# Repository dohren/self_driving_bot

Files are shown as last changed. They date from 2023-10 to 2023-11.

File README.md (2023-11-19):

# self-driving-bot

## Introduction

This documentation provides an overview of a ROS2 package found in a specific repository designed for transforming an Ikea changing table into a self-driving robot. This innovative project takes a budget-friendly approach by utilizing an inexpensive, second-hand Ikea changing table and equipping it with essential robotic components to enable autonomous movement.

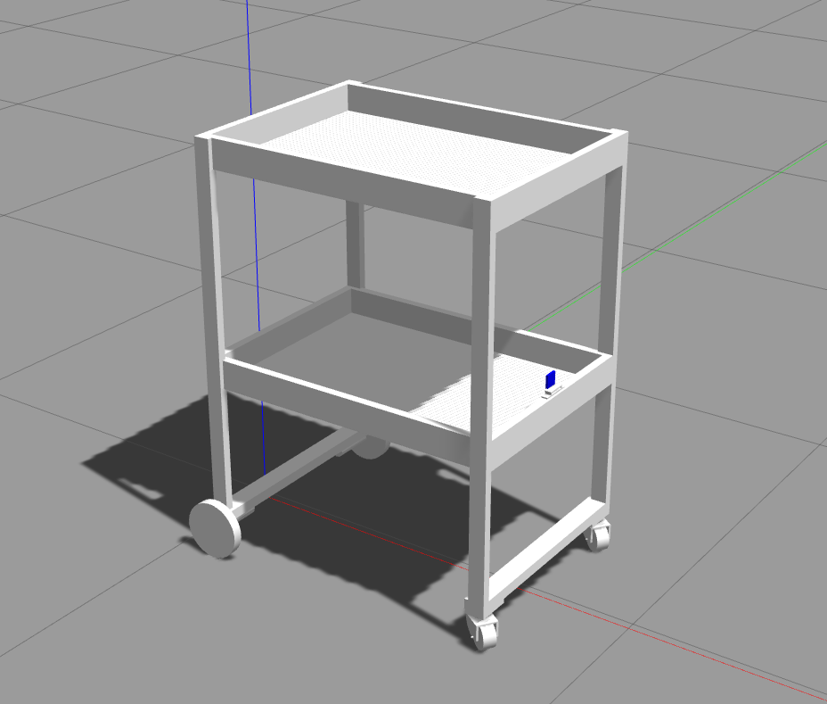
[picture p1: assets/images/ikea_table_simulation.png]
IKEA TABLE SIMULATION IKEA table simulation

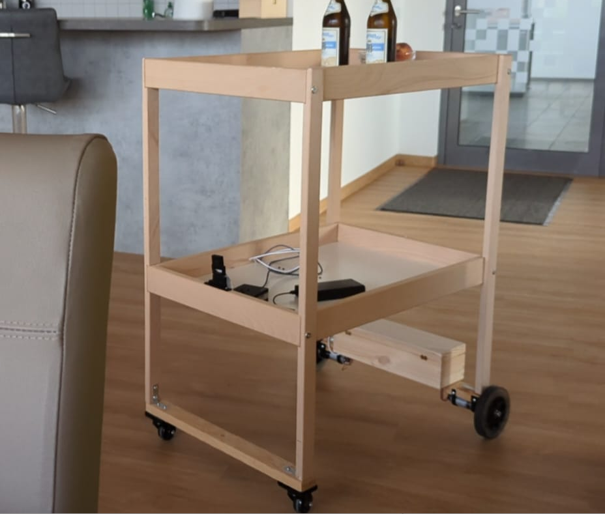
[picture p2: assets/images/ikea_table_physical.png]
IKEA TABLE PHYSICAL IKEA table physical


## Core Components and Assembly
### 1. Ikea Changing Table:

The project’s foundation is built on a used Ikea changing table, acquired at an approximate cost of 15 Euros.

### 2. Motion Mechanism:

Two 12V DC Motors: Installed at the rear to facilitate the robot’s movement.
Two Furniture Casters: Attached at the front for easy and smooth directional shifts.
Two Roof Battens: Utilized possibly for structural reinforcement or additional mounting surfaces, although the specific application is not mentioned in the initial information provided.

### 3. Control System:

Raspberry Pi 4 (4GB): Acts as the central processing unit, managing and executing the ROS2 packages and algorithms for autonomous navigation.
ESP32: Works in conjunction with a motor shield to control and manage the operations of the 12V DC motors.

### 4. Sensing and Navigation:

ydlidar: Mounted upside down on the lower plate, it scans the robot’s environment to assist in navigation and obstacle avoidance.
Camera: Installed on the robot but not employed for navigation or control functions in the current configuration.
Motor Decoders: Attached to the 12V DC motors to gather data on the robot’s movement, assisting in precise navigation and control.

## Working Mechanism

The autonomous Ikea table robot is powered and controlled by the synergy of the Raspberry Pi and ESP32. The Raspberry Pi, loaded with ROS2 packages, processes the data received from the ydlidar and motor decoders to make real-time decisions for navigation and obstacle avoidance.

The 12V DC motors, governed by the ESP32 with a motor shield, are responsible for the robot’s movement. The ydlidar, strategically placed, continually scans the environment, feeding data back to the central processing system for informed and responsive navigational adjustments.

## Conclusion

This ROS2 package exemplifies an innovative, budget-conscious approach to autonomous robotics. By converting an Ikea changing table into a self-driving entity, this project demonstrates the potential for creating functional robotic systems without a significant financial investment while promoting recycling and upcycling practices in robotics development.

# Robots

## Box Robot

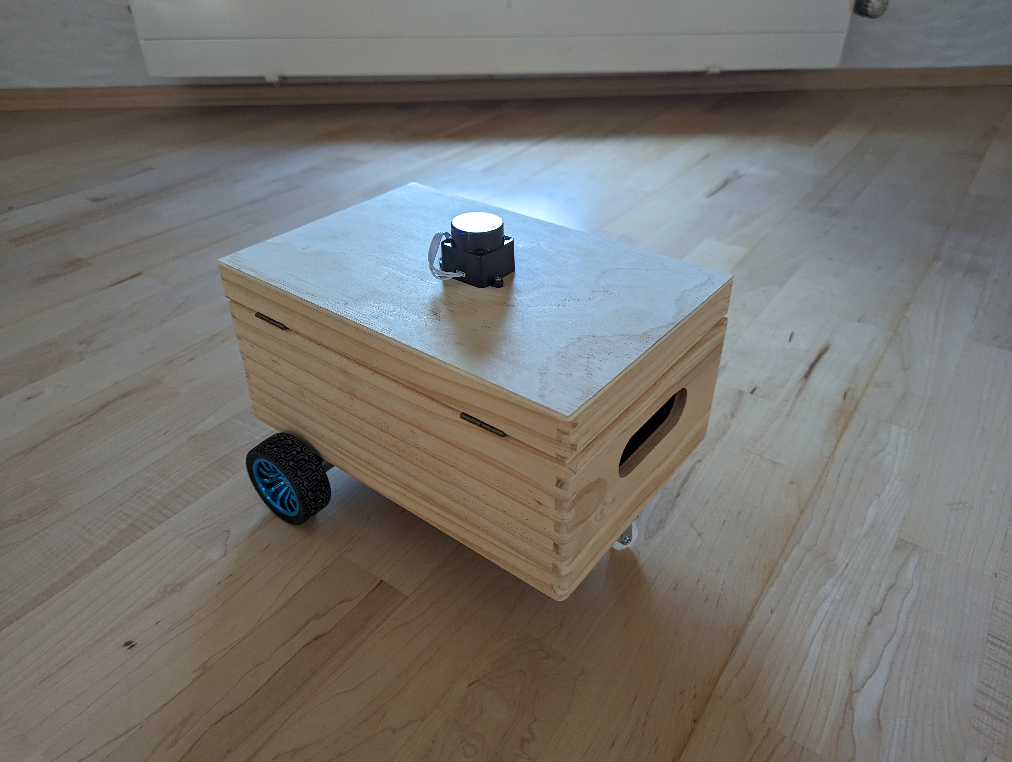
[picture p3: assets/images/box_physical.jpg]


### Parts
| | Product | Seller | Price |
| :---: | :---: | :---: | :---: |
| Motor | 2 x DC 12 V DIY Encoder Getriebemotor | [Amazon](https://www.amazon.de/Getriebemotor-Halterung-Magnetgetriebe-Drehzahlreduzierung-Vollmetallgetriebe/dp/B07WRYQZNR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) |  40,39 € |
| Micro Processor | ESP32 Dev Board | [Amazon](https://www.amazon.de/AZDelivery-NodeMCU-Development-Nachfolgermodell-ESP8266/dp/B074RGW2VQ) | 9,99 € |
| Mini Computer | Raspberry Pi 4 Model B 4GB | [Amazon](https://www.amazon.de/Raspberry-SD-Karte-Ultimatives-Quad-Core-unterst%C3%BCtzt/dp/B082PSBBMM) | 149,99 € |
| Lidar Sensor | IdLidar LD19 | [Amazon](https://www.amazon.de/InnoMaker-Extra-Small-Resistance-brushless-Navigation/dp/B09VKZ9YNT) |  90,00 € |
| 12v DC Akku | Eleoption DC12300 Super-Akku | [Amazon](https://www.amazon.de/3000-mAh-dc12300-Super-wiederaufladbar-St%C3%B6psel-baterias/dp/B06ZYQPK3P) |  29,99 € |
| 5v USB Akku | Power Bank 26800mAh Akku | [Amazon](https://www.amazon.de/Power-Bank-26800mAh-Externer-Akku/dp/B08FCLJ9N1) |  19,99 € |
| Chassis | Box | [laublust](https://www.laublust.de/products/holzkiste-mit-deckel-natur-unbehandelt-fsc%C2%AE-erinnerungsbox-gross-klein-aufbewahrungskiste-aus-holz-diverse-grossen) |  9,99 € |
| Plugs | QitinDasen 12 | [Amazon](https://www.amazon.de/QitinDasen-Verbinder-Terminalblock-M%C3%A4nnlich-Weiblich/dp/B07MF69TMX) | 6,98 € |
| Cables | Breadboard jumpers | [Amazon](https://www.amazon.de/dp/B0BRM568FM/ref=sspa_dk_detail_0) |  9,99 € |
| USB Cables | Micro USB / USB C | |  10,00 € |
| Front Roller | Micro USB / USB C | [Amazon](https://www.amazon.de/Smart-Chassis-Motors-Encoder-Battery/dp/B01LXY7CM3) |  16,79 € |
| Gamepad | Wireless Controller | [Amazon](https://www.amazon.de/iNNEXT-Controller-USB-Empf%C3%A4nger-Nintendo-Spiele-Unterst%C3%BCtzung/dp/B07FTCWBSY) |  11,50 € |
| Total | | | 365.23 € |

### Software

| | Software | 
| :---: | :---: |
| Raspberry OS | [Ubuntu for Raspberry PI](https://ubuntu.com/download/raspberry-pi/thank-you?version=22.04.3&architecture=desktop-arm64+raspi) |
| Ros2 | [ROS2 Humble](https://docs.ros.org/en/humble/index.html) |
| Navigation | [Ros2 Nav2](https://navigation.ros.org/) |
| micro-ROS | [micro-ROS](https://github.com/micro-ROS/micro_ros_arduino) |
| Visual Studio Code | [VSCode](https://code.visualstudio.com/) |
| Rufus | [micro-ROS](https://rufus.ie/de/) |
| Arduino IDE | [Arduino IDE](https://www.arduino.cc/en/software) | 
| Lidar Driver | [ldlidar_stl_ros2](https://github.com/ldrobotSensorTeam/ldlidar_stl_ros2) |

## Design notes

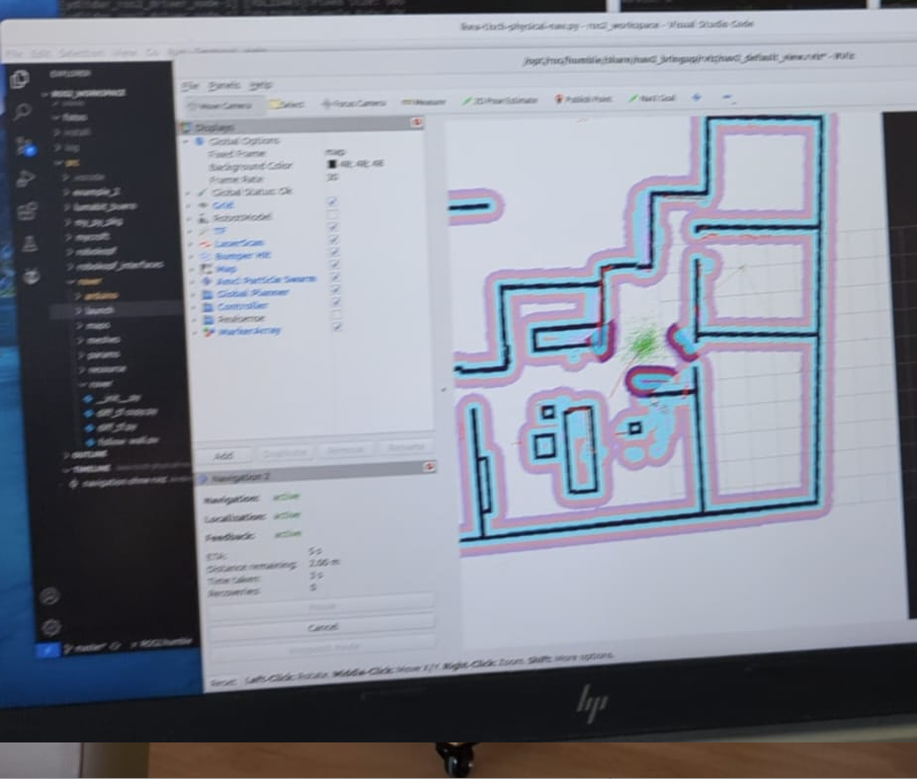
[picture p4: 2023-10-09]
assets/images/ikea_table_rviz.png

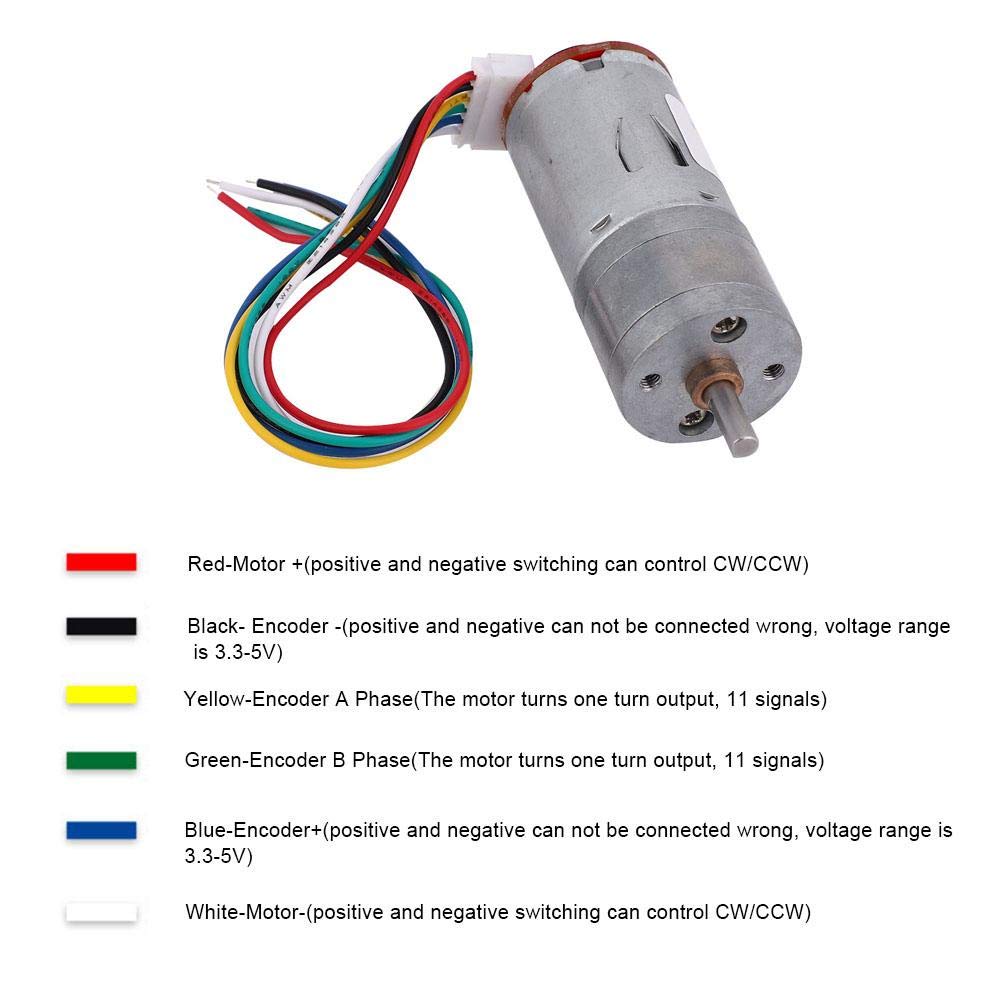
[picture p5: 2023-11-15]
assets/images/12v_dc_motor_with_encoder.jpg

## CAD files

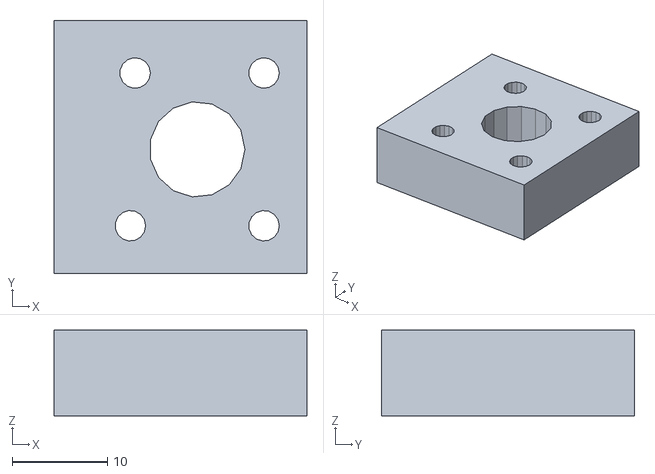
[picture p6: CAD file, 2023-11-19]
assets/3dprint/AufhaengungMotorKiste.stl
26.5 x 26.5 x 9.00

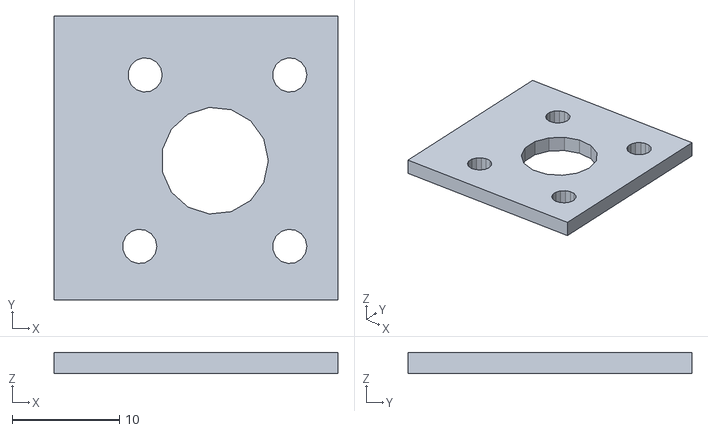
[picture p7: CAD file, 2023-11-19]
assets/3dprint/AufhaengungMotorBoxDuenn.stl
26.5 x 26.5 x 2.00

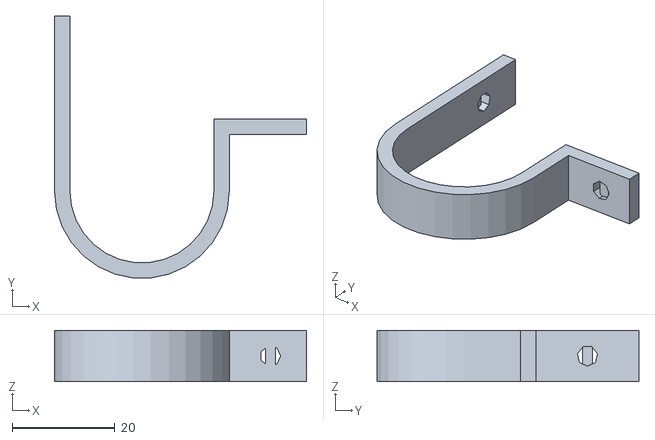
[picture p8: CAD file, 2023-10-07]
assets/3dprint/AufhaengungMotor.stl
49.0 x 50.9 x 10.0

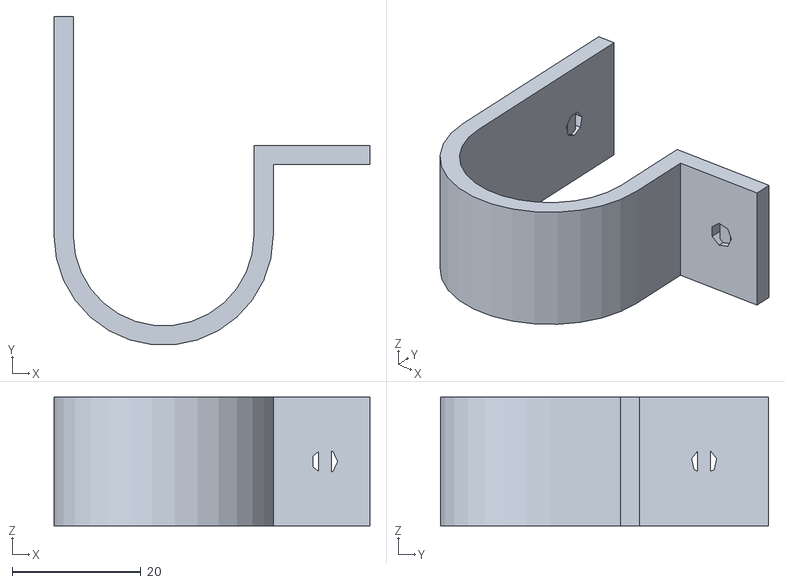
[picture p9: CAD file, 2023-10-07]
assets/3dprint/AufhängungMotor.stl
49.0 x 50.9 x 20.0

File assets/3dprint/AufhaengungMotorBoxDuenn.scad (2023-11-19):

difference() {
    union() {
        cube([26.5,26.5,2]);
    }
    translate([22,5,-1]) cylinder(r=1.6, h=11, $fn=15);
    translate([8,5,-1]) cylinder(r=1.6, h=11, $fn=15);
    translate([8.5,21,-1]) cylinder(r=1.6, h=11, $fn=15);
    translate([22,21,-1]) cylinder(r=1.6, h=11, $fn=15);
    translate([15,13,-1]) cylinder(r=5, h=11, $fn=15);
}
/*
translate([-11,-11,0] ) {
    #cube([22,22,20]);
}

translate([-6,-6,0] ) {
    #cube([12,12,10]);
}*/

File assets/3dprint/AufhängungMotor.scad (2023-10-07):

breite = 10;

difference() {
    cylinder(r=17, h= breite);
    translate([0,0,-1]) cylinder(r=14, h=(breite + 2));
    translate ([-17,0,-1]) cube([34,17,breite + 2]);
}

translate ([-17,0,0]) cube([3,34,breite]);
translate ([14,0,0]) cube([3,14,breite]);

difference() {
        translate ([15,11,0]) cube([17,3,breite]);
        #translate ([-14, 14,-1]) cube([47,24,breite + 2]);
}


/*
module aufhaengung() {
    difference() {
        translate ([0,0,0]) cube([20,100,10]);
        translate([10,10,-1]) cylinder(r=5, h=12);
    }
}

module schraube() {
    rotate(a=[270,0,0]) cylinder(r=2, h=22);
}


translate ([0,0,0]) aufhaengung();
translate ([0,0,30]) aufhaengung();

difference() {
    translate([0,100,0]) cube([120,20,40]);
    translate([50,99,10]) schraube();
    translate([50,99,30]) schraube();
    translate([80,99,10]) schraube();
    translate([80,99,30]) schraube();
}

module prism(l, w, h){
   rotate(a=[0,90,0]) polyhedron(
       points=[[0,0,0], [l,0,0], [l,w,0], [0,w,0], [0,w,h], [l,w,h]],
       faces=[[0,1,2,3],[5,4,3,2],[0,4,5,1],[0,3,4],[5,2,1]]
   );
}
translate([0,80,10]) cube([20,20,20]);
translate([20,80,00]) prism (-40,20,20);

difference() {
        translate([100,90,0]) cube([20,10,40]);
        translate([110,95,-1]) cylinder(r=2, h=42);
        translate([99,89,15]) cube([22,11,10]);
    
}
*/

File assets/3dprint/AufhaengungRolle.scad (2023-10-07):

module loch() {
    cube([20,20,11]);
}


module aufhaengung() {
    difference() {
        translate ([0,0,0]) cube([51,71,9]);
        translate ([5,5,-1]) loch();
        translate ([26,5,-1]) loch();
        translate ([5,46,-1]) loch();
        translate ([26,46,-1]) loch();   
        translate ([-1,28,4]) cube([53,15,6]);             
    }
}

aufhaengung();

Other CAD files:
assets/3dprint/AufhaengungMotorKiste.scad

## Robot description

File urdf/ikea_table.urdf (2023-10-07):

<?xml version="1.0" ?>
<robot name="ikea_table">


  <link name="base_link">
   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

    <inertial>
      <origin xyz="0.35000000 -0.00000000 0.50000000"/>
      <mass value="4.00000000"/>
      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
    </inertial>

  </link>


  <link name="base_footprint"/>

  <joint name="base_joint" type="fixed">
    <parent link="base_footprint"/>
    <child link="base_link" />
    <origin xyz="0 0 0.50" rpy="0 0 0"/>
  </joint>

  <link name="wheel_back_left">
    <inertial>
      <origin xyz="0.00000000 -0.00000000 -0.00000000" rpy="-1.57 0.0 0.0"/>
      <mass value="0.25000000"/>
      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
    </inertial>

    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
  </link>

  <joint name="wheel_back_left_joint" type="continuous">
    <origin xyz="-0.0 0.29 0.0" rpy="0.0 -1.57 -1.57"/>
    <parent link="base_link"/>
    <child link="wheel_back_left"/>
    <axis xyz="0.0 0.0 1.0"/>
  </joint>

  <link name="wheel_back_right">
    <inertial>
      <origin xyz="0.00000000 -0.00000000 -0.00000000" rpy="-1.57 0.0 0.0"/>
      <mass value="0.25000000"/>
      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
    </inertial>

    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
  </link>

  <joint name="wheel_back_right_joint" type="continuous">
    <origin xyz="0.0 -0.29 0.0" rpy="0.0 -1.57 -1.57"/>
    <parent link="base_link"/>
    <child link="wheel_back_right"/>
    <axis xyz="0.0 0.0 1.0"/>
  </joint>

  <link name="roll_front_right">
   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

    <inertial>
      <origin xyz="-0.00000000 0.00688662 -0.02194443"/>
      <mass value="0.20000000"/>
      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
    </inertial>

  </link>

  <joint name="roll_front_right_joint" type="continuous">
    <origin xyz="0.68 -0.24 0.0" rpy="0.0 0.0 0.0"/>
    <parent link="base_link"/>
    <child link="roll_front_right"/>
    <axis xyz="0.0 0.0 1.0"/>
  </joint>


  <link name="wheel_front_right">
    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

    <inertial>
      <origin xyz="0.00000000 0.00000000 0.00000000"/>
      <mass value="0.10000000"/>
      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
    </inertial>

    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
  </link>

  <joint name="wheel_front_right_joint" type="continuous">
    <origin xyz="0.0 0.02 -0.040" rpy="0.0 1.57 0.0"/>
    <parent link="roll_front_right"/>
    <child link="wheel_front_right"/>
    <axis xyz="0.0 0.0 1.0"/>
  </joint>

<link name="roll_front_left">
   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

    <inertial>
      <origin xyz="-0.00000000 0.00688662 -0.02194443"/>
      <mass value="0.20000000"/>
      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
    </inertial>

  </link>

  <joint name="roll_front_left_joint" type="continuous">
    <origin xyz="0.68 0.24 0.0" rpy="0.0 0.0 0.0"/>
    <parent link="base_link"/>
    <child link="roll_front_left"/>
    <axis xyz="0.0 0.0 1.0"/>
  </joint>


  <link name="wheel_front_left">
    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

    <inertial>
      <origin xyz="0.00000000 0.00000000 0.00000000"/>
      <mass value="0.10000000"/>
      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
    </inertial>

    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

  </link>

  <joint name="wheel_front_left_joint" type="continuous">
    <origin xyz="-0.0 0.02 -0.040" rpy="0.0 1.57 0.0"/>
    <parent link="roll_front_left"/>
    <child link="wheel_front_left"/>
    <axis xyz="0.0 0.0 1.0"/>
  </joint>

  <link name="camera">
    <inertial>
            <mass value="0.01" />
            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
    </inertial>

    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
  </link>

  <joint name="camera_joint" type="fixed">
    <origin xyz="0.68 0.0175 0.433" rpy="0 0.0 0.0"/>
    <parent link="base_link"/>
    <child link="camera"/>
    <axis xyz="0.0 0.0 1.0"/>

  </joint>

  <link name="lidar">
    <inertial>
            <mass value="0.1" />
            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
    </inertial>

    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
  </link>

  <joint name="lidar_joint" type="fixed">
    <origin xyz="0.34 0.0 0.305" rpy="0.0 0.0 0.0"/>
    <parent link="base_link"/>
    <child link="lidar"/>
    <axis xyz="0.0 0.0 1.0"/>
  </joint>

   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 
  

</robot>

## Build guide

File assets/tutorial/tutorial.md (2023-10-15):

## Introduction

Installation
* https://docs.ros.org/en/humble/index.html
* https://navigation.ros.org/getting_started/index.html
* clone repo in workspace/src folder and source ~/ros2/ros2_workspace/install/setup.bash

YdLidar konfigurieren:
* https://github.com/YDLIDAR/YDLidar-SDK
* git clone git@github.com:dohren/ydlidar_ros2_driver.git and checkout ikea-tisch-fix

Run Simulation
* Download models
* fix /ros2_workspace/src/self_driving_bot/urdf/ikea_table.urdf path in filename
* add following line to ~/.bashrc
    export GAZEBO_MODEL_PATH=~/ros2/ros2_workspace/src/self_driving_bot/models:$GAZEBO_MODEL_PATH
    source ~/.bashrc 
* ros2 launch self_driving_bot self_driving_bot_simulation_navigation.py

Gazebo not opening
* ps -aef | grep gazebo 
* kill -9 pid

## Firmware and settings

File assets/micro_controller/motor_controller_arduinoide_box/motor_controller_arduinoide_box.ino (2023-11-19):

#include <micro_ros_arduino.h>

#include <stdio.h>
#include <rcl/rcl.h>
#include <rcl/error_handling.h>
#include <rclc/rclc.h>
#include <rclc/executor.h>
#include <rmw_microros/rmw_microros.h>

#include <geometry_msgs/msg/twist.h>

#include <std_msgs/msg/int32.h>
#include <ESP32Encoder.h>

#define RCCHECK(fn) { rcl_ret_t temp_rc = fn; if((temp_rc != RCL_RET_OK)){error_loop();}}
#define RCSOFTCHECK(fn) { rcl_ret_t temp_rc = fn; if((temp_rc != RCL_RET_OK)){error_loop();}}
#define RCCHECK(fn) { rcl_ret_t temp_rc = fn; if((temp_rc != RCL_RET_OK)){return false;}}
#define EXECUTE_EVERY_N_MS(MS, X)  do { \
  static volatile int64_t init = -1; \
  if (init == -1) { init = uxr_millis();} \
  if (uxr_millis() - init > MS) { X; init = uxr_millis();} \
} while (0)\

const int r1=27,r2=26,l1=14,l2=12,speedr=25,speedl=13;

rcl_subscription_t subscriber;
rcl_publisher_t publisher_left;
rcl_publisher_t publisher_right;
geometry_msgs__msg__Twist msg;
std_msgs__msg__Int32 msg_publisher_left;
std_msgs__msg__Int32 msg_publisher_right;
rclc_executor_t executor;
rclc_executor_t executor_publisher;
rcl_allocator_t allocator;
rclc_support_t support;
rcl_node_t node;
rcl_timer_t timer;

int speed_factor = 50;
const int turn_interval = 50; // Adjust this value to control the turn interval (in milliseconds)

float global_left_speed = 0;
float global_right_speed = 0;
float global_interval = 0;
unsigned long previousMillis = -5000; 

ESP32Encoder encoder_left;
ESP32Encoder encoder_right;

void error_loop(){
  while(1){
    delay(100);
  }
}

enum states {
  WAITING_AGENT,
  AGENT_AVAILABLE,
  AGENT_CONNECTED,
  AGENT_DISCONNECTED
} state;

void timer_callback(rcl_timer_t * timer, int64_t last_call_time)
{  
  RCLC_UNUSED(last_call_time);
  if (timer != NULL) {
    
    msg_publisher_left.data = (int32_t)encoder_left.getCount();
    msg_publisher_right.data = (int32_t)encoder_right.getCount();
    RCSOFTCHECK(rcl_publish(&publisher_left, &msg_publisher_left, NULL));
    RCSOFTCHECK(rcl_publish(&publisher_right, &msg_publisher_right, NULL));
    
  }
}

void move_rover(float lspeed, float rspeed) {

  if (lspeed > 0) {
    digitalWrite(l1,LOW);
    digitalWrite(l2,HIGH);
    analogWrite(speedl, lspeed); 
  }
  else if (lspeed < 0) {
    digitalWrite(l1,HIGH);
    digitalWrite(l2,LOW);
    analogWrite(speedl, -lspeed);     
  }
  else {
    digitalWrite(l1,LOW);
    digitalWrite(l2,LOW);
    analogWrite(speedl, 0);    
  }

  if (rspeed > 0) {
    digitalWrite(r1,HIGH);
    digitalWrite(r2,LOW);
    analogWrite(speedr, rspeed); 
  }
  else if (rspeed < 0) {
    digitalWrite(r1,LOW);
    digitalWrite(r2,HIGH);
    analogWrite(speedr, -rspeed);     
  }
  else {
    digitalWrite(r1,LOW);
    digitalWrite(r2,LOW);
    analogWrite(speedr, 0);    
  }
  
}

//twist message cb
void subscription_callback_simple(const void *msgin) {
  // Cast the received message to the appropriate type
  const geometry_msgs__msg__Twist *msg = (const geometry_msgs__msg__Twist *)msgin;

  // Extract linear and angular velocities from the message
  float linear_velocity = msg->linear.x;
  float angular_velocity = msg->angular.z;
  
  // Initialize left and right wheel speeds
  float left_speed = 0;
  float right_speed = 0;
  float interval = 0;

  // Check the type of movement based on the angular velocity
  if (angular_velocity > 0.1) {
    // Robot is turning right
    left_speed = -200;  
    right_speed = 200;
    interval = angular_velocity * 100;         
  } else if (angular_velocity < -0.1) {
    // Robot is turning left 
    left_speed = 200;
    right_speed = -200;               
    interval = -angular_velocity * 100;
  } else if (linear_velocity > 0.1) {
    // Robot is moving forward
    left_speed = 200;  
    right_speed = 200;
  } else if (linear_velocity < -0.1) {
    // Robot is moving backward
    left_speed = -200;  
    right_speed = -200;   
  } 

  global_left_speed = left_speed;
  global_right_speed = right_speed;
  global_interval = interval;

}



void setup() {
  Serial.begin(115200);
  set_microros_transports();

  //ESP32Encoder::useInternalWeakPullResistors=DOWN;
  // Enable the weak pull up resistors
  ESP32Encoder::useInternalWeakPullResistors=UP;

  // use pin 19 and 18 for the first encoder
  encoder_left.attachHalfQuad(35, 34);
  // use pin 17 and 16 for the second encoder
  encoder_right.attachHalfQuad(33, 32);

  pinMode(l1,OUTPUT);   //left motors forward
  pinMode(l2,OUTPUT);
  pinMode(r1,OUTPUT);   //right motors forward
  pinMode(r2,OUTPUT);   //right motors reverse
  pinMode(speedl,OUTPUT);
  pinMode(speedr,OUTPUT);

  delay(1000);

  state = WAITING_AGENT;
  
  delay(100);
}

bool create_entities() {

  allocator = rcl_get_default_allocator();

   //create init_options
  RCCHECK(rclc_support_init(&support, 0, NULL, &allocator));

  // create node
  RCCHECK(rclc_node_init_default(&node, "micro_ros_arduino_node", "", &support));

  // create subscriber
  RCCHECK(rclc_subscription_init_default(
    &subscriber,
    &node,
    ROSIDL_GET_MSG_TYPE_SUPPORT(geometry_msgs, msg, Twist),
    "cmd_vel"));

  // create publisher
  RCCHECK(rclc_publisher_init_default(
    &publisher_left,
    &node,
    ROSIDL_GET_MSG_TYPE_SUPPORT(std_msgs, msg, Int32),
    "lwheel"));


  // create publisher
  RCCHECK(rclc_publisher_init_default(
    &publisher_right,
    &node,
    ROSIDL_GET_MSG_TYPE_SUPPORT(std_msgs, msg, Int32),
    "rwheel"));


  // create timer,
  const unsigned int timer_timeout = 100;
  RCCHECK(rclc_timer_init_default(
    &timer,
    &support,
    RCL_MS_TO_NS(timer_timeout),
    timer_callback));

  // create executor
  executor = rclc_executor_get_zero_initialized_executor();
  RCCHECK(rclc_executor_init(&executor, &support.context, 1, &allocator));
  RCCHECK(rclc_executor_add_subscription(&executor, &subscriber, &msg, &subscription_callback_simple, ON_NEW_DATA));
  
  // create executor_publisher
  RCCHECK(rclc_executor_init(&executor_publisher, &support.context, 1, &allocator));
  RCCHECK(rclc_executor_add_timer(&executor_publisher, &timer));

  return true;
}

void destroy_entities()
{
  rmw_context_t * rmw_context = rcl_context_get_rmw_context(&support.context);
  //(void) rmw_uros_set_context_entity_destroy_session_timeout(rmw_context, 0);

  rcl_publisher_fini(&publisher_left,  &node);
  rcl_publisher_fini(&publisher_right, &node);
  rcl_timer_fini(&timer);
  rclc_executor_fini(&executor);
  rclc_executor_fini(&executor_publisher);
  rcl_node_fini(&node);
  rclc_support_fini(&support);
}

void loop() {
  
 // delay(100);
  switch (state) {
    case WAITING_AGENT:
      EXECUTE_EVERY_N_MS(500, state = (RMW_RET_OK == rmw_uros_ping_agent(100, 1)) ? AGENT_AVAILABLE : WAITING_AGENT);
      break;
    case AGENT_AVAILABLE:
      state = (true == create_entities()) ? AGENT_CONNECTED : WAITING_AGENT;
      if (state == WAITING_AGENT) {
        destroy_entities();
      };
      break;
    case AGENT_CONNECTED:
      EXECUTE_EVERY_N_MS(200, state = (RMW_RET_OK == rmw_uros_ping_agent(100, 1)) ? AGENT_CONNECTED : AGENT_DISCONNECTED);
      if (state == AGENT_CONNECTED) {
        if (millis() - previousMillis > 400 ) {
              move_rover(global_left_speed, global_right_speed);
          
              if (global_interval > 0 ){ 
                previousMillis = millis();
                delay(global_interval);
                move_rover(0, 0);
              }
          }
          rclc_executor_spin_some(&executor, RCL_MS_TO_NS(100));
          rclc_executor_spin_some(&executor_publisher, RCL_MS_TO_NS(100));
      }
      break;
    case AGENT_DISCONNECTED:
      destroy_entities();
      state = WAITING_AGENT;
      break;
    default:
      break;
  }
}

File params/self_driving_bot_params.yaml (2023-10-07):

ydlidar_ros2_driver_node:
  ros__parameters:
    port: /dev/ttyUSB0
    frame_id: laser
    ignore_array: ""
    baudrate: 230400
    lidar_type: 1
    device_type: 0
    sample_rate: 9
    abnormal_check_count: 4
    resolution_fixed: true
    reversion: true
    inverted: true
    auto_reconnect: true
    isSingleChannel: false
    intensity: false
    support_motor_dtr: false
    angle_max: 180.0
    angle_min: -180.0
    range_max: 64.0
    range_min: 0.01
    frequency: 10.0
    invalid_range_is_inf: false
  
slam_toolbox:
  ros__parameters:
    solver_plugin: solver_plugins::CeresSolver
    ceres_linear_solver: SPARSE_NORMAL_CHOLESKY
    ceres_preconditioner: SCHUR_JACOBI
    ceres_trust_strategy: LEVENBERG_MARQUARDT
    ceres_dogleg_type: TRADITIONAL_DOGLEG
    ceres_loss_function: None

    # ROS Parameters
    odom_frame: odom
    map_frame: map
    base_frame: base_link
    scan_topic: /scan
    mode: mapping #localization

    # if you'd like to start localizing on bringup in a map and pose
    #map_file_name: test_steve
    #map_start_pose: [5.0, 1.0, 0.0]

    debug_logging: false
    throttle_scans: 1
    transform_publish_period: 0.02 #if 0 never publishes odometry
    map_update_interval: 5.0
    resolution: 0.05
    max_laser_range: 20.0 #for rastering images
    minimum_time_interval: 0.5
    transform_timeout: 0.2
    tf_buffer_duration: 30.
    stack_size_to_use: 40000000 #// program needs a larger stack size to serialize large maps

    # General Parameters
    use_scan_matching: true
    use_scan_barycenter: true
    minimum_travel_distance: 0.5
    minimum_travel_heading: 0.5
    scan_buffer_size: 3
    scan_buffer_maximum_scan_distance: 10.0
    link_match_minimum_response_fine: 0.1  
    link_scan_maximum_distance: 1.5
    do_loop_closing: true 
    loop_match_minimum_chain_size: 3
    loop_match_maximum_variance_coarse: 3.0  
    loop_match_minimum_response_coarse: 0.35    
    loop_match_minimum_response_fine: 0.45

    # Correlation Parameters - Correlation Parameters
    correlation_search_space_dimension: 0.5
    correlation_search_space_resolution: 0.01
    correlation_search_space_smear_deviation: 0.1 

    # Correlation Parameters - Loop Closure Parameters
    loop_search_space_dimension: 8.0
    loop_search_space_resolution: 0.05
    loop_search_space_smear_deviation: 0.03
    loop_search_maximum_distance: 3.0

    # Scan Matcher Parameters
    distance_variance_penalty: 0.5      
    angle_variance_penalty: 1.0    

    fine_search_angle_offset: 0.00349     
    coarse_search_angle_offset: 0.349   
    coarse_angle_resolution: 0.0349        
    minimum_angle_penalty: 0.9
    minimum_distance_penalty: 0.5
    use_response_expansion: true

amcl:
  ros__parameters:
    use_sim_time: True
    alpha1: 0.2
    alpha2: 0.2
    alpha3: 0.2
    alpha4: 0.2
    alpha5: 0.2
    base_frame_id: "base_link"
    beam_skip_distance: 0.5
    beam_skip_error_threshold: 0.9
    beam_skip_threshold: 0.3
    do_beamskip: false
    global_frame_id: "map"
    lambda_short: 0.1
    laser_likelihood_max_dist: 2.0
    laser_max_range: 100.0
    laser_min_range: -1.0
    laser_model_type: "likelihood_field"
    max_beams: 60
    max_particles: 2000
    min_particles: 500
    odom_frame_id: "odom"
    pf_err: 0.05
    pf_z: 0.99
    recovery_alpha_fast: 0.0
    recovery_alpha_slow: 0.0
    resample_interval: 1
    robot_model_type: "nav2_amcl::DifferentialMotionModel"
    save_pose_rate: 0.5
    sigma_hit: 0.2
    tf_broadcast: true
    transform_tolerance: 1.0
    update_min_a: 0.2
    update_min_d: 0.25
    z_hit: 0.5
    z_max: 0.05
    z_rand: 0.5
    z_short: 0.05
    scan_topic: scan

amcl_map_client:
  ros__parameters:
    use_sim_time: True

amcl_rclcpp_node:
  ros__parameters:
    use_sim_time: True
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

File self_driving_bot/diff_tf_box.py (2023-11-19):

#!/usr/bin/env python
#
# Copyright (C) 2012 Jon Stephan.
#
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
# ----------------------------------
# Portions of this code borrowed from the arbotix_python diff_controller.
#
# diff_controller.py - controller for a differential drive
# Copyright (c) 2010-2011 Vanadium Labs LLC.  All right reserved.
#
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

import rclpy
from rclpy.node import Node
from math import sin, cos, pi

from geometry_msgs.msg import Quaternion
from geometry_msgs.msg import Twist
from geometry_msgs.msg import TransformStamped
from nav_msgs.msg import Odometry
from tf2_ros import TransformBroadcaster
from std_msgs.msg import Int32

NS_TO_SEC= 1000000000

class DiffTf(Node):
    """
       diff_tf.py - follows the output of a wheel encoder and
       creates tf and odometry messages.
       some code borrowed from the arbotix diff_controller script
       A good reference: http://rossum.sourceforge.net/papers/DiffSteer/
    """

    def __init__(self):
        super().__init__(node_name='diff_tf2')
        self.nodename = "diff_tf"
        self.get_logger().info(f"-I- {self.nodename} started")

        #### parameters #######
        self.rate_hz = self.declare_parameter("rate_hz", 10.0).value # the rate at which to publish the transform
        self.create_timer(1.0/self.rate_hz, self.update)  

        self.ticks_meter = float(
            self.declare_parameter('ticks_meter', 7800).value)  # The number of wheel encoder ticks per meter of travel
        self.base_width = float(self.declare_parameter('base_width', 0.24).value)  # The wheel base width in meters

        self.base_frame_id = self.declare_parameter('base_frame_id',
                                                    'base_link').value  # the name of the base frame of the robot

        self.odom_frame_id = self.declare_parameter('odom_frame_id',
                                                    'odom').value  # the name of the odometry reference frame

        self.encoder_min = self.declare_parameter('encoder_min', -32768).value
        self.encoder_max = self.declare_parameter('encoder_max', 32768).value
        self.encoder_low_wrap = self.declare_parameter('wheel_low_wrap', (
                self.encoder_max - self.encoder_min) * 0.3 + self.encoder_min).value
        self.encoder_high_wrap = self.declare_parameter('wheel_high_wrap', (
                self.encoder_max - self.encoder_min) * 0.7 + self.encoder_min).value

        # internal data
        self.enc_left = None  # wheel encoder readings
        self.enc_right = None
        self.left = 0.0  # actual values coming back from robot
        self.right = 0.0
        self.lmult = 0.0
        self.rmult = 0.0
        self.prev_lencoder = 0
        self.prev_rencoder = 0
        self.x = 0.0  # position in xy plane
        self.y = 0.0
        self.th = 0.0
        self.dx = 0.0  # speeds in x/rotation
        self.dr = 0.0
        self.then = self.get_clock().now()

        # subscriptions
        self.create_subscription(Int32, "lwheel", self.lwheel_callback, 10)
        self.create_subscription(Int32, "rwheel", self.rwheel_callback, 10)
        self.odom_pub = self.create_publisher(Odometry, "odom", 10)
        self.odom_broadcaster = TransformBroadcaster(self)


    def update(self):
        now = self.get_clock().now()
        elapsed = now - self.then
        self.then = now
        elapsed = elapsed.nanoseconds / NS_TO_SEC

        # calculate odometry
        if self.enc_left == None:
            d_left = 0
            d_right = 0
        else:
            d_left = (self.left - self.enc_left) / self.ticks_meter
            d_right = (self.right - self.enc_right) / self.ticks_meter
        self.enc_left = self.left
        self.enc_right = self.right

        # distance traveled is the average of the two wheels 
        d = (d_left + d_right) / 2
        # this approximation works (in radians) for small angles
        th = (d_right - d_left) / self.base_width
        # calculate velocities
        self.dx = d / elapsed
        self.dr = th / elapsed

        if d != 0:
            # calculate distance traveled in x and y
            x = cos(th) * d
            y = -sin(th) * d
            # calculate the final position of the robot
            self.x = self.x + (cos(self.th) * x - sin(self.th) * y)
            self.y = self.y + (sin(self.th) * x + cos(self.th) * y)
        if th != 0:
            self.th = self.th + th

        # publish the odom information
        quaternion = Quaternion()
        quaternion.x = 0.0
        quaternion.y = 0.0
        quaternion.z = sin(self.th / 2)
        quaternion.w = cos(self.th / 2)

        transform_stamped_msg = TransformStamped()
        transform_stamped_msg.header.stamp = self.get_clock().now().to_msg()
        transform_stamped_msg.header.frame_id = self.odom_frame_id
        transform_stamped_msg.child_frame_id = self.base_frame_id
        transform_stamped_msg.transform.translation.x = self.x
        transform_stamped_msg.transform.translation.y = self.y
        transform_stamped_msg.transform.translation.z = 0.0
        transform_stamped_msg.transform.rotation.x = quaternion.x
        transform_stamped_msg.transform.rotation.y = quaternion.y
        transform_stamped_msg.transform.rotation.z = quaternion.z
        transform_stamped_msg.transform.rotation.w = quaternion.w

        self.odom_broadcaster.sendTransform(transform_stamped_msg)

        odom = Odometry()
        odom.header.stamp = now.to_msg()
        odom.header.frame_id = self.odom_frame_id
        odom.pose.pose.position.x = self.x
        odom.pose.pose.position.y = self.y
        odom.pose.pose.position.z = 0.0
        odom.pose.pose.orientation = quaternion
        odom.child_frame_id = self.base_frame_id
        odom.twist.twist.linear.x = self.dx
        odom.twist.twist.linear.y = 0.0
        odom.twist.twist.angular.z = self.dr
        self.odom_pub.publish(odom)
        

    def lwheel_callback(self, msg):
        enc = msg.data
        if enc < self.encoder_low_wrap and self.prev_lencoder > self.encoder_high_wrap:
            self.lmult = self.lmult + 1

        if enc > self.encoder_high_wrap and self.prev_lencoder < self.encoder_low_wrap:
            self.lmult = self.lmult - 1

        self.left = 1.0 * (enc + self.lmult * (self.encoder_max - self.encoder_min))
        self.prev_lencoder = enc
        #print("Left: " + str(msg.data))

    def rwheel_callback(self, msg):
        enc = msg.data
        if enc < self.encoder_low_wrap and self.prev_rencoder > self.encoder_high_wrap:
            self.rmult = self.rmult + 1

        if enc > self.encoder_high_wrap and self.prev_rencoder < self.encoder_low_wrap:
            self.rmult = self.rmult - 1

        self.right = 1.0 * (enc + self.rmult * (self.encoder_max - self.encoder_min))
        self.prev_rencoder = enc
        #print("Right: " + str(msg.data))
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

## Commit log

2023-10-07 test_zone world added
    [ikea_table.urdf]
2023-10-07 3dprints added
    [AufhaengungMotor.stl, AufhaengungRolle.scad, AufhängungMotor.scad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]
2023-10-15 model add for simuliation, resouce gibt hub fetch_gazebo
    [model.sdf]
2023-11-19 Feature/box motor configuration (#2)
    * Bilder entfernt
    * added Documentation for box robot
    * added Documentation for box robot
    * added Documentation for box robot
    * added Documentation for box robot
    [AufhaengungMotor.stl, AufhaengungMotorBoxDuenn.scad, AufhaengungMotorBoxDuenn.stl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]

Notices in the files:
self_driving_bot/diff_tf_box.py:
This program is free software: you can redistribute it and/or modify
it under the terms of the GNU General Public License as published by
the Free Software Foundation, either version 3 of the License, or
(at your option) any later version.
